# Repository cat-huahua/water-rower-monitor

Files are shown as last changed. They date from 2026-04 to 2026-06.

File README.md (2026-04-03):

# Water Rower Monitor

ESP32-S3 replacement console for WaterRower machines. The original monitor was destroyed by leaking batteries — this project replaces it with modern hardware and adds WiFi workout logging.

## Overview

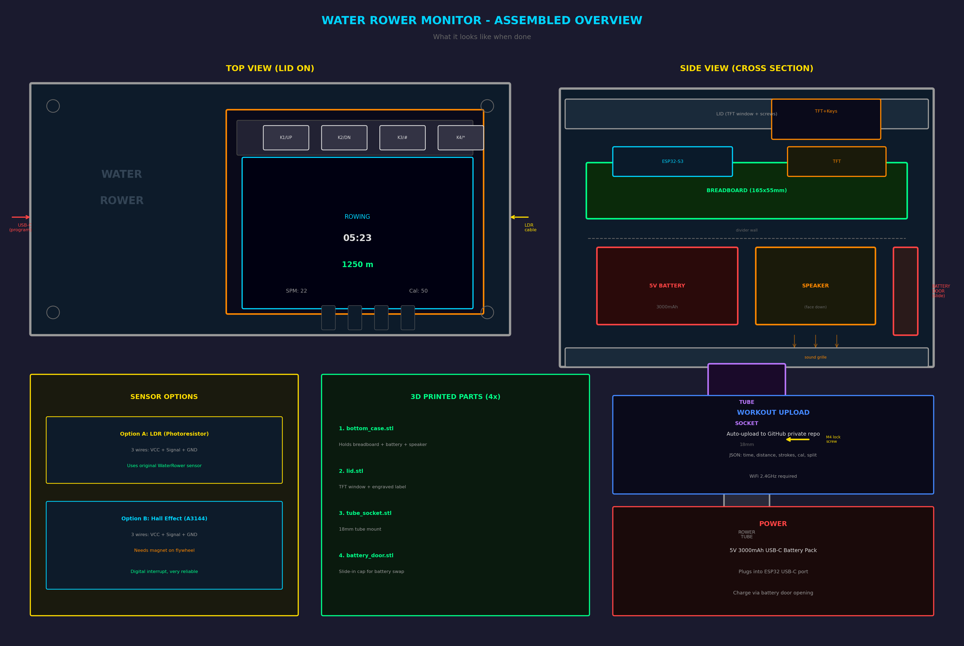
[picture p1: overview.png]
Assembled Overview


## Features

- Real-time display: time, distance, split/500m, stroke rate, calories
- 1.8" color TFT screen (ST7735S 128x160) with 4 built-in keys
- Supports **two sensor types** — choose in config.h:
  - **LDR**: Original WaterRower optical sensor (no modifications needed)
  - **Hall**: A3144 hall effect sensor + magnet on flywheel
- Speaker for audio feedback (start/stop/button sounds)
- Automatic workout upload to a private GitHub repo as JSON
- Workout history browsing (last 10 sessions)
- Adjustable screen brightness
- Powered by 5V USB-C battery pack (3000mAh)
- 3D printable enclosure with slide-in battery door

## Hardware

| Component | Details |
|---|---|
| MCU | ESP32-S3 DevKitC-1 |
| Display | ST7735S 1.8" 128x160 RGB TFT (with 4 keys) |
| Sensor | LDR (original 3-wire) **or** Hall effect (A3144 + magnet) |
| Audio | Small oval speaker (PWM driven) |
| Power | 5V 3000mAh 18650 USB-C battery pack |
| Board | Large half breadboard (165x55mm) |
| Mount | 18mm tube socket (fits original WaterRower arm) |

## Wiring

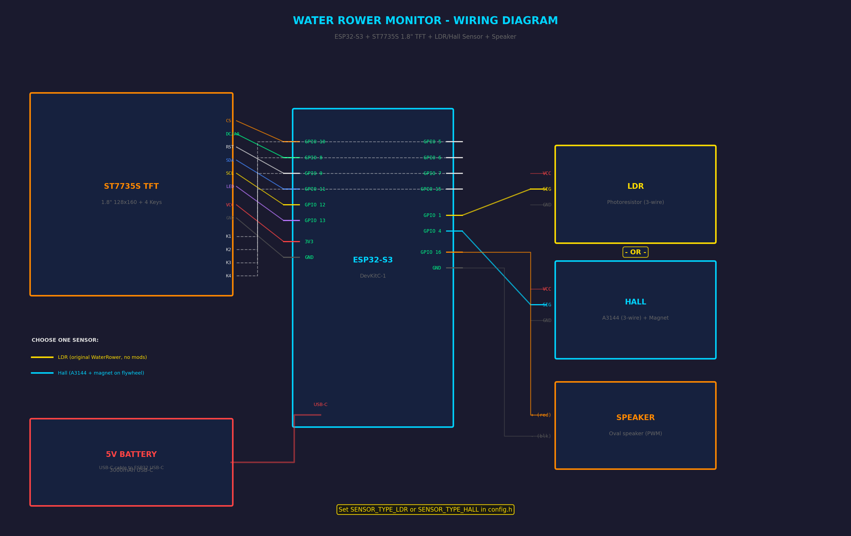
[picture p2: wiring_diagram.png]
Wiring Diagram


See [WIRING.md](WIRING.md) for detailed pin assignments.

## Assembly

See [APPLY.md](APPLY.md) for step-by-step assembly guide with photos.

## Setup

1. Copy the config template:
   ```bash
   cp firmware/include/config.h.example firmware/include/config.h
   ```

2. Edit `firmware/include/config.h` with your:
   - WiFi SSID and password
   - GitHub personal access token and repo info
   - Sensor type: uncomment `SENSOR_TYPE_LDR` or `SENSOR_TYPE_HALL`

3. Create a **private** GitHub repo for workout logs, with a `workouts/` folder

4. Flash the firmware:
   ```bash
   cd firmware
   pio run -t upload
   ```

5. Export STL files from `enclosure/enclosure.scad` using OpenSCAD (F6 → F7)

## 3D Printed Parts

| Part | File | Description |
|---|---|---|
| Bottom case | `bottom_case.stl` | Holds breadboard, battery, speaker |
| Lid | `lid.stl` | TFT window + engraved label |
| Tube socket | `tube_socket.stl` | 18mm mount for WaterRower arm |
| Battery door | `battery_door.stl` | Slide-in cap for battery swap |

## Controls

| Key | Idle | Rowing | Paused |
|-----|---|---|---|
| * | Start | — | Resume |
| # | History | Pause | End + Upload |
| UP | Brightness+ | — | — |
| DOWN | Brightness- | — | — |

## Workout Data

Each workout is saved as JSON to your private GitHub repo:

```json
{
  "machine_sn": "132224",
  "date": "2026-04-02T18:30:25Z",
  "duration_sec": 1800,
  "distance_m": 6500,
  "strokes": 450,
  "calories": 260,
  "split_500m": "2:18"
}
```

## Calibration

1. Power on — idle screen shows live LDR value
2. Set `LDR_THRESHOLD` to midpoint between light/dark readings
3. Row 10 strokes, compare displayed distance to actual
4. Adjust `METERS_PER_PULSE` accordingly

## License

[MIT](LICENSE)

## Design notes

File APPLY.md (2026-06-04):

# Water Rower Monitor — 组装指南

> 划船机: Water Rower USA | SN: 132224
> MCU: ESP32-S3 DevKitC-1
> 屏幕: ST7735S 1.8" 128x160 RGB TFT (自带4按键 K1/K2/#/*)
> 传感器: 光敏电阻 LDR (原机自带, 4线 JST 插头)
> 音频: 椭圆喇叭 (非蜂鸣器)
> 载板: 大半板面包板 830孔 (165x55mm)
> 安装: 管插式 18mm (复用原机金属管)

---

## 第一步：准备材料

### 电子元件

| 序号 | 元件 | 数量 | 备注 |
|---|---|---|---|
| 1 | ESP32-S3 DevKitC-1 | 1 | USB-C |
| 2 | 1.8" TFT 128x160 自带4按键模块 | 1 | 就是你手上那块 |
| 3 | 大半板面包板 830孔 | 1 | 165x55mm |
| 4 | 原机光敏电阻+4线JST线缆 | 1 | 已有! 红蓝绿黑线 |
| 5 | 椭圆喇叭 (你手上那个) | 1 | 已有! 红黑线 |
| 6 | 5V 3000mAh USB-C 电池包 | 1 | 已有! 18650 蓝壳 |
| 7 | 短 USB-C 对 USB-C 线 (~15cm) | 1 | 电池→ESP32 |
| 8 | 杜邦线 公对公 | ~15根 | |
| 9 | USB-C 数据线 (长) | 1 | 烧录+充电 |
| 10 | M2.5 小螺丝 | 4 | 固定喇叭 |

### 3D 打印件 (CR-10S)

| STL | 说明 | 填充 | 支撑 |
|-----|---|---|---|
| `bottom_case.stl` | 底壳 (面包板+电池仓+喇叭) | 20% | 无 |
| `lid.stl` | 盖子 (TFT窗口+刻字) | 20% | 无 |
| `tube_socket.stl` | 18mm管座 (插原机金属管) | 40% | 无 |
| `battery_door.stl` | 电池盖 (滑入式, 换电池用) | 30% | 无 |

> 全部 0.2mm 层高, PLA 或 PETG

### 螺丝

| 螺丝 | 数量 | 用途 |
|---|---|---|
| M3x8mm | 4 | 盖子 ↔ 底壳 |
| M3x10mm | 2 | 管座 ↔ 底壳底部 |
| M4x25mm + 螺母 | 1 | 管座锁紧螺丝 |

---

## 第二步：导出 STL

1. 安装 OpenSCAD: `sudo apt install openscad`
2. 打开 `enclosure/enclosure.scad`
3. 分四次导出:

| 步骤 | 保留的代码 | 保存为 |
|---|---|---|
| 1 | 只留 `bottom_case();` | `bottom_case.stl` |
| 2 | 只留 `lid();` (删 translate) | `lid.stl` |
| 3 | 只留 `tube_socket();` (删 translate) | `tube_socket.stl` |
| 4 | 只留 `battery_door();` (删 translate) | `battery_door.stl` |

每次: `F6` 渲染 → `F7` 导出

---

## 第三步：认识你的 TFT 模块

你的模块正面 (从照片看):

```
      K1      K2      K3/#    K4/*
    ┌─────┬─────┬──────┬──────┐
    │[btn]│[btn]│[btn] │[btn] │  ← 4个自带按键
    ├─────┴─────┴──────┴──────┤
    │                         │
    │      1.8" TFT 屏幕       │
    │      128 x 160          │
    │      RGB-TFT            │
    │                         │
    ├─────────────────────────┤
    │  ○                   ○  │  ← 螺丝孔
    └─────────────────────────┘
    ↑
   排针在这边 (左侧或底部, 看你的模块)
```

### 模块引脚 (翻到背面看丝印, 通常有这些脚):

```
VCC, GND, CS, RST, DC, SDA, SCL, LED, K1, K2, K3, K4
```

> **重要**: 拿到模块后, 看背面丝印确认每个引脚的顺序!
> 不同厂家的排列可能不同

---

## 第四步：面包板布局

```
面包板 165x55mm (从上方看)
┌──────────────────────────────────────────────────────────────┐
│  + 电源轨 (3.3V) ──────────────────────────────────────────  │
│  - 地线轨 (GND)  ──────────────────────────────────────────  │
│                                                              │
│  ┌──────────┐                          ┌──────────────────┐  │
│  │          │    跳线连接               │ TFT模块排针插这里 │  │
│  │ ESP32-S3 │  ←──────────────────────→│ (或用杜邦线连)   │  │
│  │          │                          └──────────────────┘  │
│  │          │                                                │
│  └──────────┘    LDR传感器线从这里引出 →  ──→ 右侧出线口      │
│                                                              │
│  - 地线轨 (GND)  ──────────────────────────────────────────  │
│  + 电源轨 (3.3V) ──────────────────────────────────────────  │
└──────────────────────────────────────────────────────────────┘
  ↑ USB-C 出线口                                    传感器出线口 ↑
```

- ESP32-S3 横跨中间沟槽, USB-C 朝左
- TFT 模块可以用排针直接插面包板, 或用杜邦线连

---

## 第五步：接线

### TFT 屏幕引脚 → ESP32-S3

```
TFT 模块引脚     跳线颜色(建议)    ESP32-S3
──────────────────────────────────────────
VCC              红色             3V3
GND              黑色             GND
CS               橙色             GPIO 10
RST              白色             GPIO 9
DC (A0)          绿色             GPIO 8
SDA (MOSI)       蓝色             GPIO 11
SCL (SCK)        黄色             GPIO 12
LED (背光)        紫色             GPIO 13
```

### TFT 模块自带按键 → ESP32-S3

```
模块按键引脚     功能              ESP32-S3
──────────────────────────────────────────
K1               UP (▲)           GPIO 5
K2               DOWN (▼)         GPIO 6
K3               # (停止/返回)     GPIO 7
K4               * (开始/恢复)     GPIO 15
```

> 按键的 GND 脚通常模块内部已经连好
> 如果你的模块按键没有内部下拉, 就把按键的公共脚连到 GND

### 原机 LDR 光敏电阻 (3线)

原机传感器只有 3 根线: VCC, Signal, GND

```
线缆颜色     功能                  ESP32-S3
──────────────────────────────────────────────
红色          VCC (传感器供电)      → 3.3V 电源轨
黑色          GND                  → GND 地线轨
信号线        LDR 模拟信号          → GPIO 1 (ADC)
```

> 如果不确定哪根是信号线:
> 用万用表量每根线对 GND 的电压, 遮住传感器时电压变化最大的就是信号线

### 喇叭

```
喇叭线           连接
──────────────────────────
红线 (+)          → GPIO 16
黑线 (-)          → GND
```

> 喇叭用螺丝固定在底壳内侧的 4 个安装柱上
> 喇叭正面朝下, 声音从底壳的音孔格栅出来

### 电源: 5V 3000mAh USB-C 电池包

```
电池包 (USB-C 输出) ──短USB-C线──→ ESP32-S3 (USB-C 输入)
```

- 电池放在底壳下方的电池仓里
- USB-C 线从电池仓穿到面包板区域，插 ESP32
- 换电池时，从背面滑出电池盖即可
- 充电时，把 USB-C 充电线从背面充电口插入电池包

### 电源轨 (别忘了!)

```
ESP32-S3 的 3V3  → 面包板 + 轨
ESP32-S3 的 GND  → 面包板 - 轨
```

---

## 第六步：配置软件

### 6.1 创建 GitHub 私有仓库

1. GitHub → New repository → 名称 `water-rower-logs` → **Private** → Create
2. 在仓库里创建 `workouts/` 文件夹 (添加一个 `.gitkeep` 文件)

### 6.2 生成 Token

1. GitHub → Settings → Developer settings → Personal access tokens → Tokens (classic)
2. 勾选 `repo` 权限 → Generate
3. 复制保存 (只显示一次)

### 6.3 修改 config.h

```cpp
// ===== 必须改 =====
#define WIFI_SSID     "你家WiFi名"
#define WIFI_PASSWORD "你家WiFi密码"
#define GITHUB_TOKEN  "ghp_你的token"
#define GITHUB_OWNER  "你的GitHub用户名"
#define GITHUB_REPO   "water-rower-logs"
```

### 6.4 确认按键引脚

**你的 TFT 模块按键引脚可能和默认不同!**

1. 看模块背面丝印, 找到 K1/K2/K3/K4 对应的引脚编号
2. 用万用表蜂鸣档测: 按下按键, 看哪个排针脚和 GND 通
3. 对应修改 `config.h`:

```cpp
#define BTN_UP_PIN    GPIO_NUM_?    // K1 对应的脚
#define BTN_DOWN_PIN  GPIO_NUM_?    // K2 对应的脚
#define BTN_HASH_PIN  GPIO_NUM_?    // K3/# 对应的脚
#define BTN_STAR_PIN  GPIO_NUM_?    // K4/* 对应的脚
```

---

## 第七步：烧录

```bash
cd ~/water-rower-monitor/firmware
pio run -t upload
pio device monitor        # 看调试输出
```

> ESP32-S3 烧录失败? 按住 BOOT → 插USB → 松开 → 重新 upload

---

## 第八步：组装

### 8.1 面包板装入底壳

```
侧面图:
┌─────────────────────────────┐  ← 盖子
│  ┌─── TFT 模块从窗口露出 ──┐│
│  │  [K1][K2][#][*]         ││  ← 按键朝上
│  │  ┌──────────────┐       ││
│  │  │   TFT 屏幕   │       ││
│  │  └──────────────┘       ││
│  └─────────────────────────┘│
│  ┌─────────────────────────┐│
│  │       面包板              ││  ← 面包板放在支撑台上
│  │   ESP32-S3 + 跳线        ││
│  └─────────────────────────┘│
└──────────────┬──────────────┘  ← 底壳
               │
         ┌─────┴─────┐
         │  管座      │          ← 管座螺丝固定在底壳底部
         │  ┌─────┐  │
         │  │金属管│  │          ← 原机的金属管插入管座
         │  │ 22mm│  │
         │  └─────┘  │
         │  锁紧螺丝→ ●          ← M4 螺丝锁紧
         └───────────┘
```

### 8.2 组装顺序

1. **面包板放入底壳** — 卡在四角支撑台上
2. **ESP32-S3 插面包板** — USB-C 朝左对准开口
3. **接好所有跳线** — 按第五步接线
4. **TFT 模块连线** — 排针插面包板或杜邦线连
5. **TFT 模块朝上** — 屏幕和按键面朝盖子方向
6. **盖盖子** — TFT 从窗口露出, 4 颗 M3 螺丝固定
7. **管座装底部** — 2 颗 M3 螺丝从底壳内侧拧入管座
8. **LDR 传感器 3 线从右侧槽口穿出**
9. **USB 线从左侧孔穿出**

### 8.3 安装到划船机

1. **量金属管直径** — 用卡尺量原机金属管外径
2. 如果不是 22mm, 改 `enclosure.scad` 里的 `tube_od = 你的数值`
3. 重新导出 `tube_socket.stl` 并打印
4. 把管座套在金属管上
5. 拧紧 M4 锁紧螺丝

### 8.4 连接原机 LDR 传感器

原机的光敏电阻传感器已经装好在飞轮位置了，你只需要把 4 线 JST 线缆连到面包板:

```
原机传感器结构 (已安装在飞轮旁):

    飞轮桨叶
    ┌───┐
    │   │  经过时遮住光线
    │   │         ↓
  [IR LED] ──光线──→ [光敏电阻 LDR]
    绿线供电              蓝线读信号

桨叶经过 → 光线被挡 → LDR 阻值变大 → 电压变化 → 检测到一个脉冲
```

- JST 线缆从外壳右侧的扁槽口穿入
- 4 根线分别插面包板对应位置
- **不需要额外传感器, 用原机自带的!**

### 8.5 安装喇叭

1. 喇叭正面 (锥面) 朝下
2. 对准底壳内侧的 4 个安装柱
3. 4 颗 M2.5 螺丝固定
4. 声音从底壳底部的格栅孔出来

---

## 第九步：校准

### 9.1 校准 LDR 阈值 (先做这个!)

1. 烧录固件后开机
2. **空闲页面会显示当前 LDR 值**: `LDR: 3200 (thr:2000)`
3. 用手遮住划船机飞轮传感器, 观察 LDR 值变化
4. 记下:
   - 不遮时 (亮) = 例如 3500
   - 遮住时 (暗) = 例如 800
5. 阈值设为中间: `LDR_THRESHOLD = (3500 + 800) / 2 = 2150`
6. 改 `config.h` → 重新烧录

### 9.2 校准距离

1. 按 `*` 开始训练
2. **慢慢均匀划 10 桨**
3. 按 `#` 暂停 → 记下距离
4. 按 `#` 结束
5. 计算:

```
新 METERS_PER_REV = 当前 METERS_PER_REV × (实际距离 / 屏幕显示距离)
```

6. 改 `config.h` 的 `METERS_PER_REV` → 重新烧录

---

## 操作说明

```
┌─────────────────────────────────────┐
│  TFT 模块按键:                       │
│  [K1/UP]  [K2/DN]  [K3/#]  [K4/*]  │
├──────┬──────────┬────────┬─────────┤
│ 按键 │   空闲   │ 训练中  │   暂停  │
├──────┼──────────┼────────┼─────────┤
│  *   │  开始    │  --    │  恢复   │
│  #   │  历史    │  暂停  │ 结束+存  │
│  UP  │  亮度+   │  --    │  --     │
│  DN  │  亮度-   │  --    │  --     │
├──────┼──────────┴────────┴─────────┤
│      │  历史查看:                    │
│  UP  │  上一条                      │
│  DN  │  下一条                      │
│  #   │  返回主页                    │
└──────┴─────────────────────────────┘
```

---

## 训练记录

自动上传到 `water-rower-logs` 仓库:

```
water-rower-logs/
└── workouts/
    ├── workout_20260402_183025.json
    └── workout_20260403_071512.json
```

JSON 内容:
```json
{
    "machine_sn": "132224",
    "machine_model": "Water Rower USA",
    "date": "2026-04-02T18:30:25Z",
    "duration_sec": 1800,
    "distance_m": 6500,
    "strokes": 450,
    "calories": 260,
    "avg_speed_ms": 3.61,
    "avg_stroke_rate": 15,
    "split_500m": "2:18"
}
```

---

## 故障排查

| 问题 | 解决 |
|---|---|
| 屏幕不亮 | 检查 VCC/GND, LED 背光脚 |
| 白屏 | DC/CS/RST 接线, 试 `INITR_GREENTAB` 或 `INITR_REDTAB` |
| 按键没反应 | 万用表测 K1-K4 脚, 确认 GPIO 编号对得上 |
| 距离不动 | 检查 LDR 线缆接对没, 空闲页看 LDR 值是否变化 |
| 喇叭没声 | 确认红线接 GPIO 16, 黑线接 GND |
| LDR 值不变 | 检查红线(VCC)和绿线(IR LED)是否供电 |
| WiFi 连不上 | 只支持 2.4GHz, 检查 SSID 密码 |
| 上传失败 | Token 过期 / 仓库不存在 / 没有 repo 权限 |
| 管座太松 | 拧紧 M4 锁紧螺丝, 或加一圈胶带增加摩擦 |
| 管座太紧 | 改 `tube_socket_id` 加大 0.5mm, 重新打印 |
| 烧录失败 | 按住 BOOT 键插 USB |

---

## 需要量的尺寸 (打印前必做!)

| 量什么 | 改哪里 | 当前默认值 |
|---|---|---|
| 原机金属管外径 | `enclosure.scad` → `tube_od` | 18mm (已确认) |
| 喇叭安装孔距(宽) | `enclosure.scad` → `spk_screw_spacing_w` | 48mm |
| 喇叭安装孔距(高) | `enclosure.scad` → `spk_screw_spacing_l` | 24mm |
| TFT 模块 PCB 总宽 | `enclosure.scad` → `tft_pcb_w` | 52mm |
| TFT 模块 PCB 总高 | `enclosure.scad` → `tft_pcb_l` | 40mm |
| TFT 可视区宽 | `enclosure.scad` → `tft_screen_w` | 29mm |
| TFT 可视区高 | `enclosure.scad` → `tft_screen_l` | 37mm |
| 按键条高度 | `enclosure.scad` → `tft_btn_strip_h` | 10mm |

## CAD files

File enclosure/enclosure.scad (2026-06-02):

/*
 * Water Rower Monitor Enclosure
 * Replaces original WaterRower USA monitor
 *
 * Hardware:
 *   - Large half breadboard (165x55mm)
 *   - ESP32-S3 DevKitC-1
 *   - ST7735S 1.8" 128x160 TFT with 4 built-in keys (K1,K2,#,*)
 *
 * Mounts via original tube socket (18mm rod)
 * Speaker mounted on bottom case wall
 * Printer: Creality CR-10S
 *
 * Export STL: F6 (Render) -> F7 (Export STL)
 * Print: 0.2mm layer, 20% infill, PLA/PETG
 */

$fn = 50;

// ===== Large Half Breadboard (830 holes) =====
bb_w = 165;    // long side
bb_l = 55;     // short side
bb_h = 10;     // height with pins

// ===== TFT Module (with 4 built-in keys on top edge) =====
// PCB dimensions (measure yours and adjust!)
tft_pcb_w = 52;    // total width including button strip
tft_pcb_l = 40;    // total height
tft_screen_w = 29; // visible screen area
tft_screen_l = 37; // visible screen area
tft_btn_strip_h = 10;  // button strip height above screen
// The whole front face: buttons on top, screen below
tft_front_w = tft_pcb_w;
tft_front_l = tft_screen_l + tft_btn_strip_h + 2;

// ===== Original Monitor Tube Mount =====
tube_od = 18;       // 18mm tube (measured!)
tube_socket_id = tube_od + 0.5;  // socket inner diameter (tight fit)
tube_socket_depth = 40;  // how deep the tube goes in
tube_socket_od = tube_od + 8;    // socket wall thickness

// ===== Speaker =====
// Oval speaker with mounting bracket (from photos)
spk_bracket_w = 55;   // bracket total width
spk_bracket_l = 30;   // bracket total height
spk_oval_w = 35;       // oval cone width
spk_oval_l = 24;       // oval cone height
spk_screw_spacing_w = 48;  // screw hole spacing width
spk_screw_spacing_l = 24;  // screw hole spacing height
spk_screw_d = 3;       // screw hole diameter

// ===== 5V 3000mAh USB-C Battery Pack =====
// 18650-based pack with built-in USB-C output
bat_w = 70;    // length
bat_l = 37;    // width
bat_h = 20;    // height

// ===== Enclosure =====
wall = 2.5;
corner_r = 4;
clearance = 1.5;

inner_w = bb_w + clearance * 2;
inner_l = bb_l + bat_l + clearance * 3;  // breadboard + battery side by side
inner_h = 28;

outer_w = inner_w + wall * 2;
outer_l = inner_l + wall * 2;
outer_h = inner_h + wall;

lid_h = 3.5;
lip = 1.5;

// USB cutout
usb_w = 14;
usb_h = 8;

// Sensor cable hole
cable_d = 6;

// Screw
screw_d = 2.5;
boss_d = 7;

// ===== TFT window position on lid =====
// Centered on the right half, showing screen + buttons
tft_win_x = outer_w / 2 + 5;
tft_win_y = (outer_l - tft_front_l) / 2;

// ===== Modules =====

module rounded_box(w, l, h, r) {
    hull() {
        for (x = [r, w - r])
            for (y = [r, l - r])
                translate([x, y, 0])
                    cylinder(h = h, r = r);
    }
}

// ───── Tube Socket (replaces rail clamp) ─────
module tube_socket() {
    difference() {
        union() {
            // Main socket cylinder
            cylinder(d = tube_socket_od, h = tube_socket_depth);

            // Transition flange to mount on case bottom
            translate([0, 0, tube_socket_depth - 3])
                hull() {
                    cylinder(d = tube_socket_od, h = 3);
                    // Flange ears for screw holes
                    for (a = [-1, 1])
                        translate([a * 20, 0, 0])
                            cylinder(d = 12, h = 3);
                }
        }

        // Tube hole
        translate([0, 0, -1])
            cylinder(d = tube_socket_id, h = tube_socket_depth - 3 + 2);

        // Slit for clamping (so it grips the tube)
        translate([-1, -tube_socket_od / 2 - 1, -1])
            cube([2, tube_socket_od + 2, tube_socket_depth + 2]);

        // Set screw hole (M4, to lock tube in place)
        translate([0, 0, tube_socket_depth / 2])
            rotate([0, 90, 0])
                cylinder(d = 4, h = tube_socket_od, center = true);

        // Mounting screw holes (to attach to case)
        for (a = [-1, 1])
            translate([a * 20, 0, tube_socket_depth - 5])
                cylinder(d = 3.2, h = 10);
    }
}

// ───── Bottom Case ─────
// Layout (top view):
//
//  ┌──────────────────────────────────────────────┐
//  │  ┌─────────────────────────────────────────┐ │
//  │  │         Breadboard (165x55)             │ │
//  │  └─────────────────────────────────────────┘ │
//  │  ┌──────────────┐  ┌───────┐  ┌──────────┐  │
//  │  │   Battery     │  │Speaker│  │ (wiring) │  │
//  │  │   70x37x20   │  │       │  │          │  │
//  │  └──────────────┘  └───────┘  └──────────┘  │
//  └──────────────────────────────────────────────┘
//   USB                                    LDR cable

module bottom_case() {
    // Battery area Y start (below breadboard)
    bat_area_y = wall + clearance + bb_l + clearance;

    difference() {
        rounded_box(outer_w, outer_l, outer_h, corner_r);

        // Inner cavity
        translate([wall, wall, wall])
            rounded_box(inner_w, inner_l, inner_h + 1, max(corner_r - 1, 1));

        // USB-C cutout for battery cable (left short side, lower)
        // Battery USB-C cable routes to ESP32 USB-C
        translate([-1, bat_area_y + bat_l / 2 - usb_w / 2, wall + 2])
            cube([wall + 2, usb_w, usb_h]);

        // Also a notch on left side for ESP32 USB-C (upper area, for programming)
        translate([-1, wall + clearance + bb_l / 2 - usb_w / 2, wall + 4])
            cube([wall + 2, usb_w, usb_h]);

        // LDR 3-wire cable slot (right short side)
        translate([outer_w - wall - 1, outer_l / 2 - 5, wall + bb_h + 3])
            cube([wall + 2, 10, 4]);

        // Tube socket mounting holes (bottom center)
        for (a = [-1, 1])
            translate([outer_w / 2 + a * 20, outer_l / 2, -1])
                cylinder(d = 3.2, h = wall + 2);

        // Speaker grille (bottom wall)
        spk_gx = outer_w / 2;
        spk_gy = bat_area_y + bat_l / 2;
        for (ix = [-3:3])
            for (iy = [-2:2])
                translate([spk_gx + ix * 5, spk_gy + iy * 5, -1])
                    cylinder(d = 2.5, h = wall + 2);

        // Battery door opening (back long side wall)
        // Rectangular hole to slide battery in/out
        bat_door_w = bat_w + 4;
        bat_door_h = bat_h + 2;
        translate([wall + clearance + 3, outer_l - wall - 1, wall + 1])
            cube([bat_door_w, wall + 2, bat_door_h]);

        // Battery door slide grooves (channels in the wall edges)
        // Door slides in from above
        bat_door_groove = 1.5;
        // Left groove
        translate([wall + clearance + 3 - bat_door_groove, outer_l - wall - 0.5,
                   wall + 1])
            cube([bat_door_groove, wall + 1, bat_door_h + 4]);
        // Right groove
        translate([wall + clearance + 3 + bat_door_w, outer_l - wall - 0.5,
                   wall + 1])
            cube([bat_door_groove, wall + 1, bat_door_h + 4]);

        // Charging USB-C pass-through hole (below battery door)
        translate([wall + clearance + 3 + bat_door_w / 2 - 6,
                   outer_l - wall - 1, wall + bat_door_h + 5])
            cube([12, wall + 2, 7]);
    }

    // ── Breadboard supports (upper area) ──
    ledge_h = 3;
    ledge_w = 8;
    ledge_d = 8;

    for (dx = [wall + clearance, wall + clearance + bb_w - ledge_w])
        for (dy = [wall + clearance, wall + clearance + bb_l - ledge_d])
            translate([dx, dy, wall])
                cube([ledge_w, ledge_d, ledge_h]);

    // Side rails for breadboard
    rail_h = ledge_h + bb_h + 2;
    rail_t = 1.5;
    translate([wall + clearance - rail_t, wall + clearance + 10, wall])
        cube([rail_t, bb_l - 20, rail_h]);
    translate([wall + clearance + bb_w, wall + clearance + 10, wall])
        cube([rail_t, bb_l - 20, rail_h]);

    // ── Divider wall between breadboard and battery area ──
    divider_y = wall + clearance + bb_l + clearance / 2;
    translate([wall + 10, divider_y, wall])
        cube([inner_w - 20, 1.5, inner_h * 0.6]);

    // ── Battery cradle (lower area) ──
    bat_x = wall + clearance + 5;
    bat_y = bat_area_y + 2;
    // Side lips to hold battery
    bat_lip_h = bat_h * 0.6;
    // Left lip
    translate([bat_x - 1.5, bat_y, wall])
        cube([1.5, bat_l - 4, bat_lip_h]);
    // Right lip
    translate([bat_x + bat_w, bat_y, wall])
        cube([1.5, bat_l - 4, bat_lip_h]);
    // Back stop
    translate([bat_x, bat_y + bat_l - 4, wall])
        cube([bat_w, 1.5, bat_lip_h]);
    // Front lip (with gap for cable)
    translate([bat_x, bat_y - 1.5, wall])
        cube([bat_w * 0.3, 1.5, bat_lip_h]);
    translate([bat_x + bat_w * 0.5, bat_y - 1.5, wall])
        cube([bat_w * 0.5, 1.5, bat_lip_h]);
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

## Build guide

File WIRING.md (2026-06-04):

# Water Rower Monitor - 接线图 & 配置指南 (ESP32-S3)

## 接线图

```
                   ┌────────────────────┐
                   │   ESP32-S3 DevKit   │
                   │                    │
                   │  3V3 ─────────────┐│
                   │  GND ───────────┐ ││
                   │                 │ ││
  ┌─ ST7735S TFT ─┤                 │ ││
  │  (含4按键)      │  GPIO 10 (CS) ──┼─┼┼── TFT CS
  │                │  GPIO 8  (DC) ──┼─┼┼── TFT DC/A0
  │                │  GPIO 9  (RST)──┼─┼┼── TFT RST
  │                │  GPIO 11 (MOSI)─┼─┼┼── TFT SDA
  │                │  GPIO 12 (SCLK)─┼─┼┼── TFT SCL
  │                │  GPIO 13 (BL) ──┼─┼┼── TFT LED
  │  TFT 按键:     │                 │ ││
  │  K1(UP)        │  GPIO 5  ──────┼─┼┼── K1
  │  K2(DN)        │  GPIO 6  ──────┼─┼┼── K2
  │  K3(#)         │  GPIO 7  ──────┼─┼┼── K3
  │  K4(*)         │  GPIO 15 ──────┼─┼┼── K4
  │                │                 │ ││
  │                │         3V3 ────┘ ││── TFT VCC
  │                │         GND ──────┘│── TFT GND
  └────────────────┤                    │
                   │                    │
  ┌─ 传感器 ───────┤  (原机3线, HW-487/LM393 类型)
  │  !! 需要5V !!   │  GPIO 5  ── SIG ──┤  蓝线 (数字信号)
  │                │  5Vin    ── VCC   │  红线 (必须5V!)
  │                │  GND     ── GND ──┘  绿线
  └────────────────┤                │
                   │                │
  ┌─ 喇叭 ────────┤                │
  │                │  GPIO 16 ── + │  (红线)
  │                │  GND     ── - │  (黑线)
  └────────────────┤                │
                   │                │
  ┌─ 电池 ────────┤                │
  │  5V 3000mAh   │  USB-C ← USB-C 电池包
  └────────────────┘────────────────┘
```

## ST7735S 1.8" TFT 引脚对照 (ESP32-S3)

```
TFT 引脚         →   ESP32-S3 引脚
──────────────────────────────────
GND              →   GND
VCC              →   3V3
SCL (SCK/CLK)    →   GPIO 12
SDA (MOSI/DIN)   →   GPIO 11
RST (RES)        →   GPIO 9
DC  (A0/RS)      →   GPIO 8
CS  (SS)         →   GPIO 10
LED (BLK/BL)     →   GPIO 13
K1               →   GPIO 5   (UP)
K2               →   GPIO 6   (DOWN)
K3               →   GPIO 7   (#)
K4               →   GPIO 15  (*)
```

## 原机传感器 (HW-487 / LM393 光遮断器, 已测试确认!)

```
线缆颜色       →   ESP32-S3              注意
──────────────────────────────────────────────
红 (VCC)       →   5Vin                  !! 必须 5V, 3.3V 不够 !!
绿 (GND)       →   GND
蓝 (SIG)       →   GPIO 5               数字信号, 遮光=LOW
```

> 传感器内部有 LM393 比较器 + IR LED 限流电阻
> 不需要外接电阻, 直接接就行
> 3.3V 供电 IR LED 太暗, 必须用 5V

## 喇叭

```
喇叭线         →   ESP32-S3
──────────────────────────────
红 (+)         →   GPIO 16 (PWM)
黑 (-)         →   GND
```

## 电源

```
5V 3000mAh 电池包 ──USB-C线──→ ESP32-S3 USB-C 口
```

## 面板布局 (从正面看)

```
┌──────────────────────────────────────────┐
│                                          │
│   WATER     ┌──────────────────────┐     │
│   ROWER     │ [K1] [K2] [K3] [K4] │     │
│             │  UP   DN    #    *   │     │
│             ├──────────────────────┤     │
│             │                      │     │
│             │    1.8" TFT 屏幕     │     │
│             │    128 x 160         │     │
│             │                      │     │
│             └──────────────────────┘     │
│                                          │
└──────────────────────────────────────────┘
  左侧: USB-C口 (烧录)    右侧: LDR线槽口
  背面: 电池盖 (滑入式) + 充电口
```

## 需要修改的变量

### config.h — 必须改

| 变量 | 说明 | 示例 |
|---|---|---|
| `WIFI_SSID` | 你的 WiFi 名称 | `"MyWiFi"` |
| `WIFI_PASSWORD` | WiFi 密码 | `"password123"` |
| `GITHUB_TOKEN` | GitHub Personal Access Token (repo 权限) | `"ghp_xxxx..."` |
| `GITHUB_OWNER` | GitHub 用户名 | `"my-username"` |
| `GITHUB_REPO` | 仓库名 | `"water-rower-logs"` |

### config.h — 校准后调

| 变量 | 说明 | 默认值 |
|---|---|---|
| `LDR_THRESHOLD` | LDR 脉冲检测阈值 (0-4095) | `2000` |
| `LDR_HYSTERESIS` | 防抖动余量 | `300` |
| `METERS_PER_REV` | 每圈(60脉冲)行进米数 — **标定量** | `1.4f` |
| `STROKE_MIN_MS` | 两桨最小间隔 (ms, ~100SPM 上限) | `600` |
| `STROKE_HYST` | drive/recovery 翻转阈值 (比例) | `0.06f` |

### enclosure.scad — 根据实物调

| 变量 | 说明 | 默认值 |
|---|---|---|
| `tube_od` | 原机金属管外径 | `18mm` (已确认) |
| `tft_pcb_w` | TFT 模块 PCB 总宽 | `52mm` |
| `tft_pcb_l` | TFT 模块 PCB 总高 | `40mm` |
| `tft_screen_w` | 屏幕可视区宽 | `29mm` |
| `tft_screen_l` | 屏幕可视区高 | `37mm` |
| `bat_w` | 电池包长度 | `70mm` |
| `bat_l` | 电池包宽度 | `37mm` |
| `bat_h` | 电池包厚度 | `20mm` |
| `spk_screw_spacing_w` | 喇叭螺丝孔距(宽) | `48mm` |
| `spk_screw_spacing_l` | 喇叭螺丝孔距(高) | `24mm` |

## 校准步骤

1. 开机后空闲页面会显示实时 LDR 值: `LDR: xxxx (thr:2000)`
2. 转动飞轮, 观察值的变化范围
3. 设 `LDR_THRESHOLD` 为亮/暗中间值
4. 按 * 开始训练, 划 10 桨, 记下距离
5. 计算: `新 METERS_PER_REV = 当前 METERS_PER_REV × (实际距离 / 屏幕距离)`
6. 改 config.h 的 `METERS_PER_REV`, 重新烧录

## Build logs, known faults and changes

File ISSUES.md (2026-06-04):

# 已知问题与改进建议 / Issues

针对水阻划船机（water-resistance rower）固件的分析。核心结论：**距离常数量级错误**导致距离严重偏小；**拉桨/SPM 检测模型**（靠"脉冲停 500ms"切桨）对水阻机不成立。

机器参数（用于物理估算）：水箱 D≈0.5 m，水≈17 kg，桨每转 60 脉冲。

| # | 标题 | 类型 | 优先级 |
|---|---|---|---|
| 1 | `METERS_PER_PULSE` 量级错误，距离读数偏小约 60–120× | bug | P0 |
| 2 | 标定公式自指错误 + 文档常数与代码差 60× | bug/docs | P0 |
| 3 | 拉桨次数：用"脉冲停 500ms"切桨，水阻机飞轮不停 → 整次只计 1 桨 | bug | P0 |
| 4 | SPM 是单拍瞬时值 + 基于错误桨边界 → 乱跳不准 | bug | P1 |
| 5 | 瞬时速度 / 500m split 由单个脉冲间隔算，噪声大 | bug | P1 |
| 6 | LDR 轮询采样会漏脉冲（loop 阻塞）→ 距离偏小 | bug | P1 |
| 7 | recovery 段估算有效阻力系数 k_eff（观察用显示，不参与距离） | enhancement | P2 |
| 8 | `CAL_PER_METER` 死常量，与实际卡路里公式不一致 | cleanup | P2 |
| 9 | BLE 总距离字段 16-bit，>65535 m 回绕 | bug | P3 |
| 10 | `config.h.example` 缺 CALIB_* 宏（全新 clone 编译失败）；admin 默认免密 | bug/feat | P1 |

---

## #1 — `METERS_PER_PULSE` 量级错误，距离读数偏小约 60–120× — P0

**位置**
- [`firmware/include/config.h.example:87`](firmware/include/config.h.example#L87) — `#define METERS_PER_PULSE (0.00875f / 60)` ≈ `0.0001458`
- [`firmware/src/main.cpp:1318`](firmware/src/main.cpp#L1318) — `totalMeters += newPulses * calMetersPerPulse;`
- [`firmware/src/main.cpp:1205`](firmware/src/main.cpp#L1205) — 校准屏把它当"每圈米数"显示：`calMetersPerPulse * PULSES_PER_REV` = 0.00875 m/圈

**现象**
连续划行后距离显示远小于真实值（30 分钟可能只显示几十米）。

**根因（物理估算）**
距离模型本身（线性累加 `每脉冲 × 常数`）在稳态下成立，错的是常数量级：
- 桨尖速度只能是几 m/s 量级 → 桨 ≈ 2–4 转/秒（120–240 RPM）。
- 由例子数据反推（船速 3.6 m/s ÷ ~2.5 转/秒）→ **每圈 ≈ 1.4 m，每脉冲 ≈ 0.024 m**。
- 合理区间：每脉冲 **0.015–0.03**。
- 代码现值 0.000146 → **小约 60–120×**。

**建议修复**
1. 把口径统一为"每圈米数"，只在一处明确 `÷ PULSES_PER_REV`，并加注释：
   ```c
   // 标定目标：每圈（60 脉冲）行进米数，需在真机上校准
   #define METERS_PER_REV   1.4f                      // ← 标定量（默认估算值）
   #define METERS_PER_PULSE (METERS_PER_REV / PULSES_PER_REV)
   ```
2. 默认值先置 ~0.025 m/pulse（1.4–1.5 m/圈），上机标定后微调。

**验收标准**
划一段已知/可对比距离，显示距离与真实在 ±10% 内。

---

## #2 — 标定公式自指错误 + 文档常数与代码差 60× — P0

**位置**
- [`APPLY.md:358`](APPLY.md#L358) / [`WIRING.md:156`](WIRING.md#L156) — `新值 = 实际距离 / 屏幕显示距离 × 0.00875`
- [`WIRING.md:131`](WIRING.md#L131) — 文档把 `METERS_PER_PULSE` 默认值写成 `0.00875`，但代码是 `0.00875/60`（差 60×）

**现象**
用户照文档标定，算出的值再差约 60×，越标越错。

**根因**
1. 公式把 `0.00875` 写死，只有当前值恰好等于它时才对；当前实际是 0.000146。
2. 文档没区分"每脉冲" vs "每圈"，与代码口径不一致。

**建议修复**
- 正确公式（与当前值无关）：
  ```
  新 METERS_PER_PULSE = 当前 METERS_PER_PULSE × (实际距离 / 屏幕显示距离)
  ```
- 文档统一术语：明确标注是"每脉冲"还是"每圈"，与 #1 的命名对齐。
- `CALIBRATION` 屏（[`main.cpp:1188`](firmware/src/main.cpp#L1188)）可直接显示"每圈米数"供用户对照。

---

## #3 — 拉桨次数检测模型错误（水阻机飞轮不停）— P0

**位置**
- [`firmware/src/main.cpp:1327-1345`](firmware/src/main.cpp#L1327) — `inStroke` 逻辑
- [`firmware/include/config.h.example:88`](firmware/include/config.h.example#L88) — `STROKE_GAP_MS 500`

**现象**
连续划行时拉桨次数几乎不增长（常停在 1）。

**根因**
现逻辑用"脉冲间隔 > 500 ms 才算一桨结束"切分。但水阻机回桨段水储能、桨叶持续旋转，脉冲不会停 500 ms → `inStroke` 永不复位 → 整次只 `strokeCount++` 一次。判据把"飞轮转/停"误当成了"drive/recovery"。

**建议修复**
改用**角加速度（ω 斜率）**切分一桨：
- 脉冲间隔变短（ω↑）= drive 开始 → `strokeCount++`；
- 脉冲间隔变长（ω↓）= recovery。
- 加 EMA 平滑 ω、滞回（~3–5%）与最小桨时（~600 ms，对应上限 ~100 SPM）防误计；空闲衰减。
- `STROKE_GAP_MS` 退役。

**验收标准**
慢/快划各 N 桨，计数误差 ≤ ±1 桨/分钟。

---

## #4 — SPM 单拍瞬时 + 基于错误桨边界 — P1

**位置**
- [`firmware/src/main.cpp:1330-1336`](firmware/src/main.cpp#L1330) — `strokeRate = 60000.0f / strokeInterval;`

**现象**
SPM 数字跳变剧烈、读数不可信。

**根因**
建立在 #3 的错误桨边界之上，且只取最近一次间隔（瞬时值），无平滑。

**建议修复**
- **≥10s 滑动窗口平均**：记录每桨时间戳，回溯到跨度 ≥10s，`SPM = 区间数 / 跨度 × 60`（真正的 ≥10s 平均，无固定窗量化跳变）；
- 空闲衰减到 0，并清空时间戳环，避免跨暂停误算。

依赖 #3。

---

## #5 — 瞬时速度 / 500m split 噪声大 — P1

**位置**
- [`firmware/src/main.cpp:1322-1325`](firmware/src/main.cpp#L1322) — `currentSpeed = calMetersPerPulse / (lastPulseIntervalMs/1000)`
- [`firmware/src/main.cpp:866-875`](firmware/src/main.cpp#L866) — split 由 currentSpeed 推

**现象**
速度与 /500m split 每个脉冲都跳。

**根因**
由单个脉冲间隔直接算，未平滑。

**建议修复**
对 ω（或间隔）做 EMA 后再算速度；split 随之稳定。

---

## #6 — LDR 轮询漏脉冲（距离偏小）— P1

**位置**
- [`firmware/src/main.cpp:433`](firmware/src/main.cpp#L433) — LDR 在 `loop()` 里轮询
- 阻塞源：[`playTone()` 的 `delay()`](firmware/src/main.cpp#L413)、250 ms 全屏重绘（[`REDRAW_MS`](firmware/src/main.cpp#L1524)）、上传阻塞

**现象**
仅 LDR 模式：高转速时距离偏小（漏计脉冲）。Hall / Blocker 走中断不受影响。

**修复（已做）**
- LDR 改用 **1 kHz 硬件定时器 ISR** 采样（`ldrSampleISR`）：ISR 把脉冲计入 volatile 计数器，`readSensor()` 在 loop 里只做拷贝——与 Hall/Blocker 同构。即使 250ms 重绘阻塞 loop，脉冲也不丢，距离精确。
- ISR 只在 `workoutActive` 时读 ADC（此时无 flash/NVS 写）→ ISR 内 `analogRead` 安全；采样率 1 kHz 可调。
- ⚠️ 仅编译验证，需上机确认无崩溃 / 不漏脉冲。

---

## #7 — 用 recovery 段估算有效阻力系数 k_eff（自标定）— P2 enhancement

**背景物理**
撤力后仅阻力作用：`I·dω/dt = −k·ω²` → **`1/ω` 随时间线性增长，斜率 = k/I**；等价于"脉冲间隔随时间线性变大"。
- 估计量：recovery 段对 `(1/ω, t)` 线性回归取斜率，`k = I × 斜率`，`I ≈ 0.1 kg·m²`（17 kg 刚体上限 0.53，打滑后约 1/5）。
- **水阻机注意**：水会跟着转，阻力 ∝ `(ω_桨 − ω_水)²`，`(1/ω, t)` 会上凸 → 只在 recovery **前中段固定窗口**拟合，得到的是可复现的"有效 k"，非纯物理值。

**用途（水阻机版定位）**
- 因水量固定、k 稳定，**不建议逐桨动态测**；
- 用作：① drive/recovery 判据（顺带支撑 #3/#4）；② 多桨中位数/慢平均的**自标定**，水位变了能跟。
- 距离**绝对刻度**仍需一次"划已知距离"标定（水阻机无 Concept2 magic 约定，光有 k 定不了绝对米数）。

**已实现（观察用）。** recovery 段用"`1/ω`（∝间隔）线性增长、斜率 = k/I"估出 `kEff`，多桨 EMA 平滑，显示在**暂停页**（`Drag k:`）。**不参与距离**——水阻涡流使其偏噪、且绝对刻度仍需一次已知距离标定，故仅作观察/稳定性参考。`FLYWHEEL_INERTIA`（main.cpp，默认 0.1）只缩放显示值。

---

## #8 — `CAL_PER_METER` 死常量 — P2 cleanup

**位置**
- [`firmware/include/config.h.example:89`](firmware/include/config.h.example#L89) — `#define CAL_PER_METER 0.04f`（定义但未使用）
- [`firmware/src/main.cpp:1320`](firmware/src/main.cpp#L1320) — 实际用 `totalMeters * 体重 * 0.000571f`
- [`WIRING.md:133`](WIRING.md#L133) — 文档仍列 `CAL_PER_METER`

**建议修复**
删除 `CAL_PER_METER` 与文档对应行，或统一卡路里口径（二选一），消除歧义。

---

## #9 — BLE 总距离字段 16-bit，>65535 m 回绕 — P3

**位置**
- [`firmware/src/main.cpp:570`](firmware/src/main.cpp#L570) — `uint16_t totalDist = (uint16_t)totalMeters;`（高字节写 0）

**现象**
FTMS 总距离是 uint24，但代码高字节恒 0，距离超 65.5 km 回绕（实际单次训练通常不触发）。

**修复（已做）**
`totalDist` 改 `uint32_t`，写入第三字节 `(totalDist >> 16) & 0xFF`。

---

## #10 — config.h.example 缺 CALIB 宏 + admin 默认免密 — P1

**位置** [`config.h.example`](firmware/include/config.h.example)（原先缺 `CALIB_COMBO/_LEN`、`CALIB_PASSWORD/_LEN`）

**现象** admin/calib 功能的提交加了代码但没更新模板 → **全新 clone 编译失败**。

**修复（已做）**
- 补全 4 个 CALIB 宏；
- 新增开关 `CALIB_REQUIRE_PASSWORD`，**默认 `0`（不要密码）** —— 暗号组合直接进 admin 菜单；置 `1` 才要密码。
- `main.cpp` 用 `#if CALIB_REQUIRE_PASSWORD` 决定走密码屏还是直进菜单；未定义时按 0 处理（旧 config.h 自动免密）。

---

## 实施建议（顺序）

1. **P0 一批**：#1 常数置 0.025 + #2 标定公式 + #3 ω 斜率数桨 —— 一次改 `processSensor()` + `config.h` + 文档。
2. **P1**：#4 SPM 平滑、#5 速度平滑（与 #3 共用 ω 平滑机制）、#6 LDR 中断化。
3. **P2**：#7 k_eff 自标定（先只显示观察）、#8 清理。

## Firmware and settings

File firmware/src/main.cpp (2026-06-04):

/*
 * Water Rower Monitor — ESP32-S3
 * Replacement console for Water Rower USA (SN 132224)
 *
 * Hardware:
 *   - ESP32-S3 DevKitC-1
 *   - ST7735S 1.8" 128x160 TFT with 4 built-in keys
 *   - Sensor: LDR (光敏电阻) OR Hall effect (霍尔传感器)
 *     Choose in config.h: SENSOR_TYPE_LDR or SENSOR_TYPE_HALL
 *   - Speaker (喇叭) — for sound feedback
 *   - Large half breadboard (165x55mm)
 *
 * Sensor options:
 *   LDR:  Original WaterRower optical sensor (analog read)
 *   Hall: A3144/OH3144 + magnet on flywheel (digital interrupt)
 *
 * Keys (on TFT module):
 *   * (K4)  = Start / Resume
 *   # (K3)  = Stop & save / Back
 *   UP (K1) = Scroll up / Brightness+
 *   DN (K2) = Scroll down / Brightness-
 */

#include <Arduino.h>
#include <Preferences.h>
#include <SPI.h>
#include <WiFi.h>
#include <HTTPClient.h>
#include <Adafruit_GFX.h>
#include <Adafruit_ST7735.h>
#include <ArduinoJson.h>
#include <mbedtls/base64.h>
#include <BLEDevice.h>
#include <BLEServer.h>
#include <BLEUtils.h>
#include <BLE2902.h>
#include "config.h"

// Compile-time sensor check
#if !defined(SENSOR_TYPE_LDR) && !defined(SENSOR_TYPE_HALL) && !defined(SENSOR_TYPE_BLOCKER)
  #error "Define SENSOR_TYPE_LDR, SENSOR_TYPE_HALL, or SENSOR_TYPE_BLOCKER in config.h"
#endif
#if (defined(SENSOR_TYPE_LDR) + defined(SENSOR_TYPE_HALL) + defined(SENSOR_TYPE_BLOCKER)) > 1
  #error "Only define ONE sensor type in config.h"
#endif

// ───────── Pixel Art Bitmaps (16x16, 1bpp) ─────────

// Rowing person (stick figure rowing)
static const uint8_t bmp_rower[] PROGMEM = {
    0b00000110, 0b00000000,
    0b00001111, 0b00000000,
    0b00000110, 0b00000000,
    0b00011111, 0b10000000,
    0b00101100, 0b11000000,
    0b01001100, 0b00110000,
    0b00001100, 0b00001000,
    0b00011110, 0b00000000,
    0b00110011, 0b00000000,
    0b01100001, 0b10000000,
    0b00000000, 0b11100000,
    0b00000000, 0b00000000,
    0b01111111, 0b11111110,
    0b11111111, 0b11111111,
    0b01111111, 0b11111110,
    0b00111001, 0b11001100,
};

// Water wave
static const uint8_t bmp_wave[] PROGMEM = {
    0b00000000, 0b00000000,
    0b00000000, 0b00000000,
    0b00000000, 0b00000000,
    0b00000000, 0b00000000,
    0b00000000, 0b00000000,
    0b00000000, 0b00000000,
    0b00000000, 0b00000000,
    0b00000000, 0b00000000,
    0b00100000, 0b10000010,
    0b01010001, 0b01000101,
    0b10001010, 0b00101000,
    0b00000100, 0b00010000,
    0b00000000, 0b00000000,
    0b00100000, 0b10000010,
    0b01010001, 0b01000101,
    0b10001010, 0b00101000,
};

// Trophy / medal
static const uint8_t bmp_trophy[] PROGMEM = {
    0b00000001, 0b10000000,
    0b00000011, 0b11000000,
    0b00000011, 0b11000000,
    0b00000001, 0b10000000,
    0b00111111, 0b11111100,
    0b01111111, 0b11111110,
    0b01111111, 0b11111110,
    0b01111111, 0b11111110,
    0b00111111, 0b11111100,
    0b00011111, 0b11111000,
    0b00001111, 0b11110000,
    0b00000111, 0b11100000,
    0b00000011, 0b11000000,
    0b00000011, 0b11000000,
    0b00000111, 0b11100000,
    0b00001111, 0b11110000,
};

// Fire / flame
static const uint8_t bmp_fire[] PROGMEM = {
    0b00000001, 0b00000000,
    0b00000011, 0b00000000,
    0b00000011, 0b10000000,
    0b00000111, 0b10000000,
    0b00001111, 0b11000000,
    0b00001111, 0b11000000,
    0b00011111, 0b11100000,
    0b00011111, 0b11100000,
    0b00111111, 0b11110000,
    0b00111101, 0b11110000,
    0b01111100, 0b11111000,
    0b01111000, 0b11111000,
    0b01111000, 0b01111000,
    0b01111100, 0b01111000,
    0b00111111, 0b11110000,
    0b00001111, 0b11000000,
};

// Smiley face
static const uint8_t bmp_happy[] PROGMEM = {
    0b00000111, 0b11100000,
    0b00011111, 0b11111000,
    0b00111111, 0b11111100,
    0b01111111, 0b11111110,
    0b01110011, 0b11001110,
    0b11110011, 0b11001111,
    0b11111111, 0b11111111,
    0b11111111, 0b11111111,
    0b11111111, 0b11111111,
    0b11100111, 0b11100111,
    0b11110000, 0b00001111,
    0b01111000, 0b00011110,
    0b01111111, 0b11111110,
    0b00111111, 0b11111100,
    0b00011111, 0b11111000,
    0b00000111, 0b11100000,
};

// Sad face (upload failed)
static const uint8_t bmp_sad[] PROGMEM = {
    0b00000111, 0b11100000,
    0b00011111, 0b11111000,
    0b00111111, 0b11111100,
    0b01111111, 0b11111110,
    0b01110011, 0b11001110,
    0b11110011, 0b11001111,
    0b11111111, 0b11111111,
    0b11111111, 0b11111111,
    0b11111111, 0b11111111,
    0b11111111, 0b11111111,
    0b11111000, 0b00011111,
    0b11110000, 0b00001111,
    0b01100111, 0b11100110,
    0b00111111, 0b11111100,
    0b00011111, 0b11111000,
    0b00000111, 0b11100000,
};

// Skull (battery low warning)
static const uint8_t bmp_skull[] PROGMEM = {
    0b00000111, 0b11100000,
    0b00011111, 0b11111000,
    0b00111111, 0b11111100,
    0b01111111, 0b11111110,
    0b01110011, 0b11001110,
    0b01100001, 0b10000110,
    0b01110011, 0b11001110,
    0b01111111, 0b11111110,
    0b01111111, 0b11111110,
    0b00111001, 0b10011100,
    0b00011111, 0b11111000,
    0b00001111, 0b11110000,
    0b00001010, 0b10101000,
    0b00001111, 0b11110000,
    0b00001010, 0b10101000,
    0b00001111, 0b11110000,
};

// Funny motivational messages
static const char* const fun_msgs[] = {
    "ROW ROW ROW!",
    "FEEL THE BURN!",
    "KEEP GOING!",
    "YOU GOT THIS!",
    "BEAST MODE!",
    "NO PAIN NO GAIN!",
    "FASTER FASTER!",
    "UNSTOPPABLE!",
    "LIKE A FISH!",
    "WATER WARRIOR!",
};
#define NUM_FUN_MSGS 10

static const char* const idle_msgs[] = {
    "Ready to suffer?",
    "The water awaits...",
    "Don't be lazy!",
    "Let's GOOO!",
    "Calories won't burn\nthemselves",
    "Your muscles miss you",
    "Row or regret?",
    "Just one more session",
};
#define NUM_IDLE_MSGS 8

static const char* const done_msgs[] = {
    "You survived!",
    "Not bad, human!",
    "Fish would be proud",
    "Shower time!",
    "Noodle arms yet?",
    "Champion!",
};
#define NUM_DONE_MSGS 6

// ───────── Colors ─────────
#define COL_BG        ST77XX_BLACK
#define COL_TEXT      ST77XX_WHITE
#define COL_ACCENT    ST77XX_CYAN
#define COL_VALUE     ST77XX_GREEN
#define COL_WARN      ST77XX_YELLOW
#define COL_ERROR     ST77XX_RED
#define COL_LABEL     0x7BEF
#define COL_HEADER_BG 0x000F
#define COL_DIVIDER   0x4208
#define BLUE          0x1C9F  // water blue

// ───────── Display ─────────
Adafruit_ST7735 tft = Adafruit_ST7735(TFT_CS, TFT_DC, TFT_MOSI, TFT_SCLK, TFT_RST);
uint8_t brightness = 200;

// ───────── BLE FTMS (Fitness Machine Service) ─────────
// UUIDs per Bluetooth FTMS spec
#define FTMS_SERVICE_UUID        "00001826-0000-1000-8000-00805f9b34fb"
#define ROWER_DATA_UUID          "00002AD1-0000-1000-8000-00805f9b34fb"
#define FTMS_FEATURE_UUID        "00002ACC-0000-1000-8000-00805f9b34fb"
#define FTMS_STATUS_UUID         "00002ADA-0000-1000-8000-00805f9b34fb"

BLEServer* bleServer = nullptr;
BLECharacteristic* rowerDataChar = nullptr;
BLECharacteristic* ftmsFeatureChar = nullptr;
bool bleClientConnected = false;
unsigned long lastBleUpdate = 0;
#define BLE_UPDATE_INTERVAL_MS 500

class FTMSCallbacks : public BLEServerCallbacks {
    void onConnect(BLEServer* s)    { bleClientConnected = true;  }
    void onDisconnect(BLEServer* s) { bleClientConnected = false;
        BLEDevice::startAdvertising(); }
};

// ───────── Users ─────────
static const char* const userNames[] = USER_NAMES;
int currentUser = 0;
int userScrollOffset = 0;
#define USER_VISIBLE 5   // rows that fit on screen

// ───────── NVS / Calibration ─────────
Preferences prefs;
float calMetersPerPulse = METERS_PER_PULSE;
float userWeights[USER_COUNT + 1];   // +1 for Guest (index USER_COUNT)

void loadCalibration() {
    prefs.begin("wrower", true);
    calMetersPerPulse = prefs.getFloat("mpp", METERS_PER_PULSE);
    // Heal implausible stored values (e.g. old 60x-too-small calibration)
    if (calMetersPerPulse < 0.00005f || calMetersPerPulse > 0.01f)
        calMetersPerPulse = METERS_PER_PULSE;
    for (int i = 0; i <= USER_COUNT; i++) {
        char key[6]; snprintf(key, sizeof(key), "w%d", i);
        userWeights[i] = prefs.getFloat(key, 70.0f);
    }
    prefs.end();
}
void saveCalibration() {
    prefs.begin("wrower", false);
    prefs.putFloat("mpp", calMetersPerPulse);
    prefs.end();
}
void saveWeights() {
    prefs.begin("wrower", false);
    for (int i = 0; i <= USER_COUNT; i++) {
        char key[6]; snprintf(key, sizeof(key), "w%d", i);
        prefs.putFloat(key, userWeights[i]);
    }
    prefs.end();
}

// ───────── Combo / Password detector ─────────
static const uint8_t calibCombo[]    = CALIB_COMBO;
static const uint8_t calibPassword[] = CALIB_PASSWORD;

uint8_t comboBuffer[CALIB_COMBO_LEN] = {};
uint8_t comboPos = 0;
uint8_t pwdBuffer[CALIB_PASSWORD_LEN] = {};
uint8_t pwdPos   = 0;
bool    pwdWrong = false;

void pushCombo(uint8_t btn) {
    // Shift buffer
    for (int i = 0; i < CALIB_COMBO_LEN - 1; i++) comboBuffer[i] = comboBuffer[i+1];
    comboBuffer[CALIB_COMBO_LEN - 1] = btn;
    comboPos++;
}
bool checkCombo() {
    if (comboPos < CALIB_COMBO_LEN) return false;
    for (int i = 0; i < CALIB_COMBO_LEN; i++)
        if (comboBuffer[i] != calibCombo[i]) return false;
    return true;
}

// ───────── Admin state ─────────
int adminMenuItem  = 0;   // selected menu item
int adminEditUser  = 0;   // user being edited in weight screen
#define ADMIN_MENU_COUNT 2

// Long-press * on the idle screen opens admin (robust entry: the combo is
// easy to fumble because # and a failed * both navigate away from idle).
#define ADMIN_HOLD_MS 3000
unsigned long starPressMs = 0;   // press-edge time of * on idle; 0 = not armed

// ───────── State machine ─────────
enum Screen { SCR_IDLE, SCR_USER_SELECT, SCR_WORKOUT, SCR_PAUSED, SCR_SUMMARY,
              SCR_UPLOADING, SCR_HISTORY,
              SCR_CALIB_AUTH, SCR_ADMIN_MENU, SCR_CALIB,
              SCR_ADMIN_WEIGHTS, SCR_ADMIN_WEIGHT_EDIT };
Screen currentScreen = SCR_IDLE;
int displayPage = 0;

// ───────── Sensor State ─────────
uint32_t pulseCount     = 0;
unsigned long lastPulseMs = 0;
unsigned long lastPulseUsSnap = 0;  // ISR timestamp (us) of the newest accepted pulse

// ω is averaged over a window of OMEGA_AVG_PULSES consecutive pulses (¼ rev).
// Single-pulse intervals carry slot-geometry noise (uneven disc slots) of up to
// ±10-20% at 60x the rev rate — enough to flip the drive/recovery detector even
// past a 15% hysteresis. Averaging across many slots cancels that noise.
#define OMEGA_AVG_PULSES (PULSES_PER_REV / 4)
uint32_t      omegaMarkPulses = 0;  // pulse count at start of current averaging window
unsigned long omegaMarkUs     = 0;  // ISR timestamp at start of window (0 = not seeded)

#ifdef SENSOR_TYPE_LDR
volatile bool          ldrPulseActive     = false;
volatile unsigned long ldrPulseCount      = 0;
volatile unsigned long ldrLastPulseUs     = 0;
volatile unsigned long ldrPulseIntervalUs = 0;
hw_timer_t*            ldrTimer           = nullptr;
#endif

#ifdef SENSOR_TYPE_HALL
volatile unsigned long hallLastPulseUs  = 0;
volatile unsigned long hallPulseCount   = 0;
volatile unsigned long hallPulseIntervalUs = 0;
#endif

#ifdef SENSOR_TYPE_BLOCKER
volatile unsigned long blockerLastPulseUs  = 0;
volatile unsigned long blockerPulseCount   = 0;
volatile unsigned long blockerPulseIntervalUs = 0;
#endif

// ───────── Workout state ─────────
volatile bool workoutActive = false;    // volatile: read by the LDR sampling ISR
uint32_t totalPulses    = 0;
float    totalMeters    = 0;
float    totalCalories  = 0;
uint32_t strokeCount    = 0;
float    currentSpeed   = 0;
float    strokeRate     = 0;
unsigned long workoutStartMs   = 0;
unsigned long workoutElapsedMs = 0;
unsigned long lastStrokeBoundary = 0;   // time of last drive (pull) start, for SPM
bool     inDrive = false;               // true during drive phase (flywheel accelerating)
float    emaIntervalMs   = 0;           // smoothed pulse interval (ms); omega ~ 1/interval
float    extremaInterval = 0;           // turning-point interval for stroke detection
float    emaSpeed        = 0;           // smoothed boat speed (m/s)
// SPM averaged over a trailing window of >= SPM_WINDOW_MS (tune here)
#define  SPM_WINDOW_MS   10000
#define  STROKE_TS_MAX   32
unsigned long strokeTimes[STROKE_TS_MAX] = {};
int      strokeTsHead  = 0;             // ring: next write index
int      strokeTsCount = 0;             // ring: valid entries
// Drag k_eff from recovery deceleration (observational only; NOT fed to distance)
#define  FLYWHEEL_INERTIA 0.1f          // kg*m^2 (rough; only scales displayed k_eff)
float    kEff = 0;                      // smoothed effective drag (kg*m^2)
unsigned long recoveryStartMs = 0;
float    recoveryStartInterval = 0;

// History
#define MAX_HISTORY 10
struct WorkoutRecord {
    char     date[24];
    uint32_t durationSec;
    float    distance;
    uint32_t strokes;
    float    calories;
};
WorkoutRecord history[MAX_HISTORY];
int historyCount = 0;

// ───────── Buttons ─────────
struct Button {
    uint8_t pin;
    bool    lastState;
    unsigned long lastDebounce;
    bool    pressed;
};
Button btnUp   = {BTN_UP_PIN,   true, 0, false};
Button btnDown = {BTN_DOWN_PIN, true, 0, false};
Button btnHash = {BTN_HASH_PIN, true, 0, false};
Button btnStar = {BTN_STAR_PIN, true, 0, false};
#define DEBOUNCE_MS 180

void readButton(Button &b) {
    bool state = digitalRead(b.pin);
    if (state != b.lastState && (millis() - b.lastDebounce > DEBOUNCE_MS)) {
        b.lastDebounce = millis();
        if (state == LOW) b.pressed = true;
    }
    b.lastState = state;
}

void readAllButtons() {
    readButton(btnUp);
    readButton(btnDown);
    readButton(btnHash);
    readButton(btnStar);
}

bool uiDirty = false;   // set on any consumed key press -> full redraw next refresh

bool consume(Button &b) {
    if (b.pressed) { b.pressed = false; uiDirty = true; return true; }
    return false;
}

// ───────── Speaker ─────────
void playTone(uint16_t freq, uint16_t durationMs) {
    ledcWriteTone(1, freq);
    delay(durationMs);
    ledcWriteTone(1, 0);
}

void beep() {
    playTone(TONE_BEEP, 50);
}

// ───────── Backlight ─────────
void setBacklight(uint8_t val) {
    if (TFT_BL >= 0) {
        ledcWrite(0, val);
    }
}

// ───────── Sensor Reading ─────────

#ifdef SENSOR_TYPE_LDR
// LDR is sampled by a 1 kHz hardware-timer ISR so pulses are never lost while the
// loop is busy (the periodic full-screen redraw blocks the loop for ~10-20 ms).
// The ISR only touches the ADC while a workout is active — the one window in which
// no flash/NVS writes happen — so analogRead() from the ISR is safe in this firmware.
void IRAM_ATTR ldrSampleISR() {
    if (!workoutActive) return;
    int val = analogRead(LDR_SIGNAL_PIN);
    if (!ldrPulseActive && val < (LDR_THRESHOLD - LDR_HYSTERESIS)) {
        ldrPulseActive = true;                       // falling edge: paddle passing
        unsigned long now = micros();
        if (ldrLastPulseUs > 0) ldrPulseIntervalUs = now - ldrLastPulseUs;
        ldrLastPulseUs = now;
        ldrPulseCount++;
    } else if (ldrPulseActive && val > (LDR_THRESHOLD + LDR_HYSTERESIS)) {
        ldrPulseActive = false;                      // rising edge: light restored
    }
}

void readSensor() {
    if (!workoutActive) return;

    noInterrupts();
    unsigned long pc = ldrPulseCount;
    unsigned long lp = ldrLastPulseUs;
    interrupts();

    if (pc > pulseCount) {
        lastPulseMs = millis();
        lastPulseUsSnap = lp;
        pulseCount = pc;
    }
}

int getSensorRaw() { return analogRead(LDR_SIGNAL_PIN); }
const char* getSensorLabel() { return "LDR"; }
int getSensorThreshold() { return LDR_THRESHOLD; }
#endif

#ifdef SENSOR_TYPE_HALL
void IRAM_ATTR hallISR() {
    unsigned long now = micros();
    unsigned long interval = now - hallLastPulseUs;
    if (interval > HALL_MIN_PULSE_US) {
        hallPulseIntervalUs = interval;
        hallLastPulseUs = now;
        hallPulseCount++;
    }
}

void readSensor() {
    if (!workoutActive) return;

    noInterrupts();
    unsigned long pc = hallPulseCount;
    unsigned long lp = hallLastPulseUs;
    interrupts();

    if (pc > pulseCount) {
        lastPulseMs = millis();
        lastPulseUsSnap = lp;
        pulseCount = pc;
    }
}

int getSensorRaw() { return digitalRead(HALL_SENSOR_PIN) == LOW ? 0 : 4095; }
const char* getSensorLabel() { return "HALL"; }
int getSensorThreshold() { return 0; }
#endif

#ifdef SENSOR_TYPE_BLOCKER
void IRAM_ATTR blockerISR() {
    unsigned long now = micros();
    unsigned long interval = now - blockerLastPulseUs;
    if (interval > BLOCKER_MIN_PULSE_US) {
        blockerPulseIntervalUs = interval;
        blockerLastPulseUs = now;
        blockerPulseCount++;
    }
}

void readSensor() {
    if (!workoutActive) return;

    noInterrupts();
    unsigned long pc = blockerPulseCount;
    unsigned long lp = blockerLastPulseUs;
    interrupts();

    if (pc > pulseCount) {
        lastPulseMs = millis();
        lastPulseUsSnap = lp;
        pulseCount = pc;
    }
}

int getSensorRaw() { return digitalRead(BLOCKER_SENSOR_PIN) == LOW ? 0 : 4095; }
const char* getSensorLabel() { return "BLKR"; }
int getSensorThreshold() { return 0; }
#endif

// ───────── BLE FTMS Setup & Update ─────────
void initBLE() {
    BLEDevice::init("WaterRower-" MACHINE_SN);
    bleServer = BLEDevice::createServer();
    bleServer->setCallbacks(new FTMSCallbacks());

    // FTMS Service
    BLEService* ftmsService = bleServer->createService(FTMS_SERVICE_UUID);

    // FTMS Feature (required) — declare rower support
    ftmsFeatureChar = ftmsService->createCharacteristic(
        FTMS_FEATURE_UUID, BLECharacteristic::PROPERTY_READ);
    // Fitness Machine Features: Rower supported
    // Byte 0-3: Machine Features, Byte 4-7: Target Setting Features
    uint8_t ftmsFeatures[8] = {0x00, 0x00, 0x00, 0x00, 0x00, 0x00, 0x00, 0x00};
    ftmsFeatures[0] = 0x26; // stroke rate, total distance, pace, calories
    ftmsFeatureChar->setValue(ftmsFeatures, 8);

    // Rower Data (notify)
    rowerDataChar = ftmsService->createCharacteristic(
        ROWER_DATA_UUID,
        BLECharacteristic::PROPERTY_NOTIFY);
    rowerDataChar->addDescriptor(new BLE2902());

    ftmsService->start();

    // Advertise
    BLEAdvertising* adv = BLEDevice::getAdvertising();
    adv->addServiceUUID(FTMS_SERVICE_UUID);
    adv->setScanResponse(true);
    BLEDevice::startAdvertising();
}

void updateBLE() {
    if (!bleClientConnected) return;
    if (!workoutActive) return;
    if (millis() - lastBleUpdate < BLE_UPDATE_INTERVAL_MS) return;
    lastBleUpdate = millis();

    // FTMS Rower Data format (per Bluetooth spec)
    // Flags (2 bytes) + fields
    unsigned long elapsed = workoutElapsedMs + (millis() - workoutStartMs);
    uint16_t strokeRateX2 = (uint16_t)(strokeRate * 2);  // 0.5 resolution
    uint32_t totalDist = (uint32_t)totalMeters;           // FTMS total distance is uint24 (m)
    uint16_t paceS500 = 0;
    if (currentSpeed > 0.1f) {
        paceS500 = (uint16_t)(500.0f / currentSpeed);    // seconds per 500m
    }
    uint16_t totalCal = (uint16_t)totalCalories;
    uint16_t elapsedSec = (uint16_t)(elapsed / 1000);

    // Flags: bits indicate which fields are present
    // Bit 1: stroke rate + stroke count
    // Bit 2: total distance
    // Bit 4: pace
    // Bit 9: total energy
    // Bit 11: elapsed time
    uint16_t flags = 0;
    flags |= (1 << 1);  // stroke rate present
    flags |= (1 << 2);  // total distance present
    flags |= (1 << 4);  // instantaneous pace present
    flags |= (1 << 9);  // energy present
    flags |= (1 << 11); // elapsed time present

    uint8_t data[20];
    int idx = 0;
    data[idx++] = flags & 0xFF;
    data[idx++] = (flags >> 8) & 0xFF;
    // Stroke rate (uint16, 0.5 resolution)
    data[idx++] = strokeRateX2 & 0xFF;
    data[idx++] = (strokeRateX2 >> 8) & 0xFF;
    // Stroke count (uint16)
    data[idx++] = strokeCount & 0xFF;
    data[idx++] = (strokeCount >> 8) & 0xFF;
    // Total distance (uint24, little endian)
    data[idx++] = totalDist & 0xFF;
    data[idx++] = (totalDist >> 8) & 0xFF;
    data[idx++] = (totalDist >> 16) & 0xFF;
    // Instantaneous pace (uint16, seconds per 500m)
    data[idx++] = paceS500 & 0xFF;
    data[idx++] = (paceS500 >> 8) & 0xFF;
    // Energy: total (uint16) + per hour (uint16) + per min (uint8)
    data[idx++] = totalCal & 0xFF;
    data[idx++] = (totalCal >> 8) & 0xFF;
    data[idx++] = 0; data[idx++] = 0; // cal/hour (not calculated)
    data[idx++] = 0;                   // cal/min
    // Elapsed time (uint16, seconds)
    data[idx++] = elapsedSec & 0xFF;
    data[idx++] = (elapsedSec >> 8) & 0xFF;

    rowerDataChar->setValue(data, idx);
    rowerDataChar->notify();
}

// ───────── WiFi (multi-network, auto-switch) ─────────
static const char* wifiSSIDs[]     = WIFI_SSIDS;
static const char* wifiPasswords[] = WIFI_PASSWORDS;
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
void loop() {
    readAllButtons();
    handleInput();

    // Read sensor (LDR: fast polling / Hall: ISR updates globals)
    readSensor();

    processSensor();

    // BLE broadcast
    updateBLE();

    // Upload (blocking)
    if (currentScreen == SCR_UPLOADING) {
        uint32_t durSec = workoutElapsedMs / 1000;
        saveToHistory(durSec);
        bool ok = false;
        if (currentUser == USER_COUNT) {
            // Guest: screen + BLE only, no NAS upload
            beep();
        } else {
            drawUploadingScreen();
            ok = uploadToNAS(durSec);
            if (ok) {
                playTone(TONE_UPLOAD, 200);
            } else {
                playTone(300, 500);
            }
        }
        drawSummaryScreen(ok);
        currentScreen = SCR_SUMMARY;
        lastDrawnScreen = SCR_SUMMARY;
        uiDirty = false;   // summary drawn directly; a stale flag would blank it next frame
        return;
    }

    refreshDisplay();
}

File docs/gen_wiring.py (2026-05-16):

#!/usr/bin/env python3
"""Generate breadboard top-view wiring SVG for Water Rower Monitor."""

W, H = 1100, 680

lines = [f'<svg xmlns="http://www.w3.org/2000/svg" width="{W}" height="{H}" viewBox="0 0 {W} {H}">']
lines.append('<rect width="100%" height="100%" fill="#1a1a2e"/>')
lines.append('<style>text{font-family:monospace;} .lbl{font-size:11px;fill:#ccc;} .pin{font-size:9px;} .title{font-size:13px;font-weight:bold;}</style>')

def rect(x, y, w, h, fill, stroke="#555", rx=4, sw=1.5, opacity=1.0):
    return f'<rect x="{x}" y="{y}" width="{w}" height="{h}" fill="{fill}" stroke="{stroke}" stroke-width="{sw}" rx="{rx}" opacity="{opacity}"/>'

def text(x, y, s, cls="lbl", anchor="middle", fill=None):
    f = f' fill="{fill}"' if fill else ""
    return f'<text x="{x}" y="{y}" text-anchor="{anchor}" class="{cls}"{f}>{s}</text>'

def wire(x1, y1, x2, y2, color, w=2.2):
    return f'<line x1="{x1}" y1="{y1}" x2="{x2}" y2="{y2}" stroke="{color}" stroke-width="{w}" stroke-linecap="round"/>'

def wire_path(pts, color, w=2.2):
    d = "M " + " L ".join(f"{x},{y}" for x, y in pts)
    return f'<path d="{d}" stroke="{color}" stroke-width="{w}" fill="none" stroke-linecap="round" stroke-linejoin="round"/>'

def dot(x, y, color, r=4):
    return f'<circle cx="{x}" cy="{y}" r="{r}" fill="{color}"/>'

# ── Breadboard ──────────────────────────────────────────────────────────
BB_X, BB_Y, BB_W, BB_H = 140, 230, 680, 200
RAIL_H = 18
GAP_Y = BB_Y + BB_H // 2 - 6
GAP_H = 12

lines.append(rect(BB_X, BB_Y, BB_W, BB_H, "#2d5a27", "#4a4", rx=6, sw=2))
# top half rows
lines.append(rect(BB_X+8, BB_Y+RAIL_H+4, BB_W-16, BB_H//2-RAIL_H-10, "#3a3a3a", "#555", rx=2))
# bottom half rows
lines.append(rect(BB_X+8, GAP_Y+GAP_H+2, BB_W-16, BB_H//2-RAIL_H-10, "#3a3a3a", "#555", rx=2))
# power rails top
lines.append(rect(BB_X+8, BB_Y+3, BB_W-16, RAIL_H, "#2a2a2a", "#444", rx=2))
# power rails bottom
lines.append(rect(BB_X+8, BB_Y+BB_H-RAIL_H-3, BB_W-16, RAIL_H, "#2a2a2a", "#444", rx=2))

# rail stripes
for i in range(0, BB_W-20, 16):
    lines.append(f'<line x1="{BB_X+10+i}" y1="{BB_Y+5}" x2="{BB_X+10+i}" y2="{BB_Y+RAIL_H}" stroke="#c00" stroke-width="1.5" opacity="0.7"/>')
    lines.append(f'<line x1="{BB_X+10+i}" y1="{BB_Y+BB_H-RAIL_H}" x2="{BB_X+10+i}" y2="{BB_Y+BB_H-5}" stroke="#333" stroke-width="1.5" opacity="0.7"/>')
lines.append(text(BB_X-12, BB_Y+RAIL_H, "+5V", "lbl", "end", "#f55"))
lines.append(text(BB_X-12, BB_Y+BB_H-6, "GND", "lbl", "end", "#888"))

# breadboard label
lines.append(text(BB_X+BB_W//2, BB_Y+BB_H+16, "830-hole Breadboard (165×55mm)", "lbl", "middle", "#888"))

# ── ESP32-S3 DevKitC-1 ─────────────────────────────────────────────────
ESP_X, ESP_Y = 330, 222
ESP_W, ESP_H = 310, 218
lines.append(rect(ESP_X, ESP_Y, ESP_W, ESP_H, "#1a3a5c", "#4af", rx=5, sw=2))
lines.append(text(ESP_X+ESP_W//2, ESP_Y+14, "ESP32-S3 DevKitC-1", "title", "middle", "#4af"))

# USB at top
lines.append(rect(ESP_X+ESP_W//2-18, ESP_Y-10, 36, 14, "#555", "#888", rx=3))
lines.append(text(ESP_X+ESP_W//2, ESP_Y-2, "USB-C", "lbl", "middle", "#aaa"))

# left-side pins (ESP, from top)
LEFT_PINS = [
    ("3V3",    "#f88", True),
    ("GND",    "#888", True),
    ("5V(Vin)","#f55", True),
    ("GPIO16", "#fa0", False),  # Speaker
    ("GPIO15", "#8f8", False),  # K4
    ("GPIO7",  "#8f8", False),  # K3
    ("GPIO6",  "#8f8", False),  # K2
    ("GPIO5",  "#ff0", False),  # K1 + sensor
]
RIGHT_PINS = [
    ("GND",    "#888", True),
    ("GPIO13", "#09f", False),  # BL
    ("GPIO12", "#09f", False),  # SCLK
    ("GPIO11", "#09f", False),  # MOSI
    ("GPIO10", "#09f", False),  # CS
    ("GPIO9",  "#09f", False),  # RST
    ("GPIO8",  "#09f", False),  # DC
    ("3V3",    "#f88", True),
]

PIN_START_Y = ESP_Y + 34
PIN_STEP = 20

for i, (name, color, is_pwr) in enumerate(LEFT_PINS):
    py = PIN_START_Y + i * PIN_STEP
    lines.append(f'<circle cx="{ESP_X+6}" cy="{py}" r="4" fill="{color}" stroke="#000" stroke-width="1"/>')
    lines.append(text(ESP_X+14, py+4, name, "pin", "start", color))

for i, (name, color, is_pwr) in enumerate(RIGHT_PINS):
    py = PIN_START_Y + i * PIN_STEP
    lines.append(f'<circle cx="{ESP_X+ESP_W-6}" cy="{py}" r="4" fill="{color}" stroke="#000" stroke-width="1"/>')
    lines.append(text(ESP_X+ESP_W-14, py+4, name, "pin", "end", color))

# ── TFT ST7735S module ──────────────────────────────────────────────────
TFT_X, TFT_Y = 840, 60
TFT_W, TFT_H = 130, 220
lines.append(rect(TFT_X, TFT_Y, TFT_W, TFT_H, "#1a1a4a", "#66f", rx=5, sw=2))
lines.append(text(TFT_X+TFT_W//2, TFT_Y+14, "ST7735S TFT", "title", "middle", "#66f"))
lines.append(text(TFT_X+TFT_W//2, TFT_Y+26, "1.8\" 128×160", "lbl", "middle", "#aaa"))

# TFT screen area
lines.append(rect(TFT_X+15, TFT_Y+34, TFT_W-30, 90, "#000", "#44f", rx=2))
lines.append(text(TFT_X+TFT_W//2, TFT_Y+85, "SCREEN", "lbl", "middle", "#33f"))

# TFT buttons
BTN_Y = TFT_Y + 134
for i, (lbl, clr) in enumerate([("K1","#8f8"),("K2","#8f8"),("K3","#8f8"),("K4","#8f8")]):
    bx = TFT_X + 8 + i * 29
    lines.append(rect(bx, BTN_Y, 24, 14, "#333", clr, rx=3))
    lines.append(text(bx+12, BTN_Y+10, lbl, "pin", "middle", clr))

# TFT pin list
TFT_PINS = ["GND","VCC","SCL","SDA","RST","DC","CS","BL","K1","K2","K3","K4"]
TFT_COLORS = ["#888","#f88","#09f","#09f","#09f","#09f","#09f","#09f","#8f8","#8f8","#8f8","#8f8"]
for i, (pn, pc) in enumerate(zip(TFT_PINS, TFT_COLORS)):
    py = TFT_Y + 160 + i * 0  # won't fit, show as label block
    pass

lines.append(text(TFT_X+TFT_W//2, TFT_Y+168, "GND VCC SCL SDA", "pin", "middle", "#ccc"))
lines.append(text(TFT_X+TFT_W//2, TFT_Y+180, "RST  DC  CS  BL", "pin", "middle", "#ccc"))
lines.append(text(TFT_X+TFT_W//2, TFT_Y+192, "K1  K2  K3  K4", "pin", "middle", "#ccc"))

# left connector dots on TFT
TFT_CONN = [
    ("GND", "#888"), ("3V3","#f88"),
    ("SCL","#09f"), ("SDA","#09f"), ("RST","#09f"),
    ("DC","#09f"),  ("CS","#09f"),  ("BL","#09f"),
    ("K1","#ff0"),  ("K2","#8f8"),  ("K3","#8f8"), ("K4","#8f8"),
]
for i, (pn, pc) in enumerate(TFT_CONN):
    cy = TFT_Y + 44 + i * 12
    if cy < TFT_Y + TFT_H - 5:
        lines.append(f'<circle cx="{TFT_X}" cy="{cy}" r="3.5" fill="{pc}" stroke="#000" stroke-width="1"/>')

# ── HW-487 Sensor ────────────────────────────────────────────────────────
SEN_X, SEN_Y = 860, 360
SEN_W, SEN_H = 90, 65
lines.append(rect(SEN_X, SEN_Y, SEN_W, SEN_H, "#2a1a0a", "#fa0", rx=5, sw=2))
lines.append(text(SEN_X+SEN_W//2, SEN_Y+13, "HW-487", "title", "middle", "#fa0"))
lines.append(text(SEN_X+SEN_W//2, SEN_Y+25, "OPB365T55", "lbl", "middle", "#888"))
lines.append(text(SEN_X+SEN_W//2, SEN_Y+37, "replacement", "lbl", "middle", "#888"))
SEN_PINS = [("VCC","#f55"),("GND","#888"),("SIG","#ff0")]
for i,(pn,pc) in enumerate(SEN_PINS):
    cy = SEN_Y + 48
    cx = SEN_X + 12 + i*30
    lines.append(dot(cx, cy, pc, 4))
    lines.append(text(cx, cy+13, pn, "pin", "middle", pc))
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

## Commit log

2026-04-02 Water Rower Monitor - ESP32-S3 replacement console
    [enclosure.scad]
2026-04-02 Support both LDR and Hall effect sensors (choose in config.h)
2026-04-02 Add wiring diagram image
2026-04-03 Add assembled overview diagram
2026-04-03 Add pixel art, animations, and funny messages to TFT screens
    - Splash: animated waves filling up + rower icon
    - Idle: rower + waves + rotating funny messages
    - Workout: animated rower, fire icon when fast, motivational quotes
    - Paused: skull icon + 'Tired already?'
    - Summary: trophy + smiley/sad face + funny completion messages
    - Upload: happy face + 'Don't pull the plug!'
2026-04-03 Fix LEDC API for older ESP-IDF, add missing lib deps
    [main.cpp]
2026-04-10 Add optical blocker/slot sensor support (3rd sensor option)
2026-04-12 Add Bluetooth FTMS rower service - compatible with fitness apps
    - BLE FTMS (Fitness Machine Service) with Rower Data
    - Broadcasts: stroke rate, distance, pace, calories, elapsed time
    - Works with WaterRower Connect and other FTMS-compatible apps
    - Header shows BT connection status (BT=connected, bt=waiting)
    - Device name: WaterRower-<SN>
2026-04-13 Update sensor config: confirmed HW-487/LM393 blocker on WaterRower
    Tested and confirmed:
    - Sensor type: optical interrupter with LM393 comparator
    - Wiring: Red=5V(VIN), Green=GND, Blue=SIG(GPIO5)
    - Requires 5V supply (3.3V insufficient for IR LED)
    - Signal: LOW when blocked, HIGH when clear
    - Debounce: 1500us minimum pulse interval
2026-05-14 User select screen: scrollable list, supports any number of users
    Shows 5 users at a time with ▲/▼ scroll indicators and n/total counter.
    Scroll offset tracks cursor so selected item is always visible.
2026-05-16 Guest mode: BLE + screen only, skip GitHub upload
    Guest sessions go straight to summary without uploading.
    Summary screen shows "Guest - BT only" instead of upload status.
    [main.cpp]
2026-05-16 Add breadboard top-view wiring SVG diagram
    1100×680 dark-theme SVG showing ESP32-S3, TFT, HW-487 sensor,
    speaker, and battery with color-coded wires and legend.
2026-05-22 Switch to ESP32 DevKit (regular ESP32, not S3)
    Breadboard too small for S3. Changed board to esp32dev, removed S3-specific
    USB flags, added no_ota partition scheme for 2MB app space (firmware is 1.7MB).
2026-05-22 Add multi-WiFi auto-switch support
    Scans nearby networks, matches against WIFI_SSIDS list, connects to
    the strongest signal. Config supports up to any number of networks.
2026-05-22 Update calibration: 61 pulses/rev, debounce 300us
2026-05-22 Add calibration mode with secret combo + admin password
    Combo: UP UP DOWN DOWN * # on idle screen → password screen
    Password: * * UP # → calibration screen
    Calibration: UP/DOWN adjust METERS_PER_PULSE, * saves to NVS flash.
    Value persists across reboots. Both combo & password configurable in config.h.
    [main.cpp]
2026-05-22 Expand admin mode: menu, user weights, weight-based calories
    Admin menu (after password):
    - Calibration → adjust METERS_PER_PULSE, saved to NVS
    - User Weights → per-user weight (kg), saved to NVS
    Calories now calculated from user weight: dist × weight × 0.000571.
2026-05-31 docs: add ISSUES.md — distance/stroke findings and fix plan
2026-05-31 fix: correct water-rower distance scale + rewrite stroke/SPM detection
    Distance:
    - METERS_PER_PULSE was ~60-120x too small (0.00875/60). Reframe the
    calibration constant as METERS_PER_REV (default 1.4 m/rev, physics
    estimate for this tank) and derive METERS_PER_PULSE from it.
    - Auto-heal implausible stored NVS calibration values.
    - Fix self-referential calibration formula in APPLY.md/WIRING.md
    (new = current x actual/shown, not x 0.00875).
    Stroke count & SPM:
    - Replace "pulses stopped 500ms" boundary (never true on a water rower
    whose flywheel keeps spinning) with flywheel accel/decel (omega-slope)
    drive/recovery detection.
    - Smooth pulse interval, boat speed and SPM via EMA; idle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
    [main.cpp]
2026-05-31 fix: average SPM over a >=10s sliding window instead of per-stroke EMA
    Record stroke timestamps in a ring buffer; SPM = intervals / span over the
    trailing window that covers >= SPM_WINDOW_MS (10s). True >=10s average with
    no fixed-window quantization. Ring is cleared on reset and on idle so SPM
    never spans a pause.
    [main.cpp]
2026-05-31 feat: admin access without a password by default
    config.h.example was missing the CALIB_* macros, so a fresh clone failed to
    compile. Add them, plus a CALIB_REQUIRE_PASSWORD switch defaulting to 0: the
    secret idle-screen combo opens the admin menu directly with no password.
    Set it to 1 to require the password. Undefined (old config.h) => no password.
    [main.cpp]
2026-05-31 fix: LDR timer-ISR sampling (#6) + BLE 24-bit total distance (#9)
    #6: LDR was polled in loop() and could miss pulses during the ~10-20ms
    full-screen redraw. Sample it from a 1kHz hardware-timer ISR that counts
    into a volatile counter (mirrors the Hall/Blocker pattern); readSensor()
    just copies the count, so a blocked loop never loses pulses. The ISR only
    reads the ADC while workoutActive — the window with no flash/NVS writes —
    so analogRead() from the ISR is safe.
    #9: FTMS total distance is uint24 but the high byte was hard-coded 0, so
    distance wrapped at 65535m. Write the real third byte.
    [main.cpp]
2026-06-04 feat: observational drag k_eff from recovery deceleration (#7)
    Estimate effective drag during the recovery phase: 1/omega (proportional to
    the pulse interval) grows ~linearly with slope k/I, so
    k = I * (N/2pi) * d(interval)/dt over the recovery. EMA-smoothed across
    strokes and shown on the paused screen as 'Drag k'. Observational only — it
    does NOT feed distance (water swirl makes per-stroke k noisy, and absolute
    scale still needs a known-distance calibration). FLYWHEEL_INERTIA (default
    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
2026-06-04 fix: reduce screen flicker — clear only on transition, redraw every 1s
    [main.cpp]
2026-06-04 fix: screen redraw audit, stroke detection rework, distance 0.1m display
    Display fixes:
    - uiDirty flag: interactive screens (user select, admin, calib, history)
    redraw with full clear on every key press — selection highlight moves again
    - remove misplaced fillScreen calls (inside row/wave loops, after headers)
    that erased headers or left only the last list row visible
    - text background now matches highlight bars / hint bar (no black boxes)
    - workout screen: no full clear on periodic redraw (no 1 Hz flicker)
    - idle screen: pad sensor value, clear message area (no residue)
    - fixed-width /500m split; clear stale uiDirty after direct summary draw
    Stroke detection rework:
    - omega estimated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
    [main.cpp]
2026-06-04 fix: robust admin entry (hold * 3s) + combo confirm semantics; NAS wording
    Admin entry was effectively broken:
    - the combo check pushed the * trigger into the buffer BEFORE comparing,
    so any CALIB_COMBO not ending in 3 (*) could never match
    - combo entry on idle was fragile: a stray # jumps to History and a
    failed * jumps to user select, both of which swallow further keys
    Changes:
    - * on idle now acts on release: hold >= 3 s opens admin directly;
    a short press checks the combo entered before it (* no longer part
    of the combo), otherwise proceeds to user select
    - factor admin entry into enterAdmin() (handles optional password gate)
    - config.h.example: document the new semantics, drop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
    [main.cpp]
